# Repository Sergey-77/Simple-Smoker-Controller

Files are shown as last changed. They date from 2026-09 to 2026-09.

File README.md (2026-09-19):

# [PID Temperature Controller for Charbroil Simple Smoker](https://github.com/Sergey-77/Simple-Smoker-Controller)
My smoker had random issues connecting to the phone app, which is how this project started.
The original controller uses a PWM signal with a preset duty cycle to control the smoker's temperature. I recreated this functionality in the code and added the option to integrate a thermocouple for better temperature control using PID. For this setup, I used a MAX31850K thermocouple amplifier and a Type-K thermocouple with a stainless steel tip from adafruit.com.

## Hardware Components
* Microcontroller: Compatible with either the Arduino Nano ESP32 (ESP32-S3) or NodeMCU 1.0 (ESP8266).
* Thermocouple Amplifier: Adafruit MAX31850K 1-Wire Type-K Amplifier.
* Temperature Sensor: Adafruit Type-K Thermocouple.
* Power & Actuation: Powered directly by the smoker's existing 5V power supply, driving the stock heater relay controls.

## Prerequisites
You need to install extra libraries in the Arduino IDE for the MAX31850 Thermocouple Amplifier:

* MAX31850 OneWire by Adafruit
* MAX31850 DallasTemp by Adafruit

If you are using the Arduino Nano ESP32, you need also add the following code block to OneWire.h:
```c++
#elif defined(ARDUINO_ARCH_ESP32)
#define PIN_TO_BASEREG(pin) ((volatile uint32_t *)((digitalPinToGPIONumber(pin)>31)?1:0))
#define PIN_TO_BITMASK(pin) (1 << (digitalPinToGPIONumber(pin)&31))
#define IO_REG_TYPE uint32_t
#define IO_REG_ASM
#define DIRECT_READ(base, mask) ((*((volatile uint32_t *)((base)?GPIO_IN1_REG:GPIO_IN_REG)) & (mask)) ? 1 : 0) // GPIO_IN_ADDRESS
#define DIRECT_MODE_INPUT(base, mask) (*((volatile uint32_t *)((base)?GPIO_ENABLE1_W1TC_REG:GPIO_ENABLE_W1TC_REG)) = (mask)) // GPIO_ENABLE_W1TC_ADDRESS
#define DIRECT_MODE_OUTPUT(base, mask) (*((volatile uint32_t *)((base)?GPIO_ENABLE1_W1TS_REG:GPIO_ENABLE_W1TS_REG)) = (mask)) // GPIO_ENABLE_W1TS_ADDRESS
#define DIRECT_WRITE_LOW(base, mask) (*((volatile uint32_t *)((base)?GPIO_OUT1_W1TC_REG:GPIO_OUT_W1TC_REG)) = (mask)) // GPIO_OUT_W1TC_ADDRESS
#define DIRECT_WRITE_HIGH(base, mask) (*((volatile uint32_t *)((base)?GPIO_OUT1_W1TS_REG:GPIO_OUT_W1TS_REG)) = (mask)) // GPIO_OUT_W1TS_ADDRESS
```

## Wiring Diagram
Both microcontrollers operate natively on 3.3V logic but interface cleanly with the smoker's 5V power supply.
## Cable to original control board

| Blue | Black | Red |
|---|---|---|
| +5V. | DC Common | Heater Relay 3.3V |

## Option A: Using Arduino Nano ESP32

| Target Component | Nano ESP32 Pin | Notes |
|---|---|---|
| Smoker 5V Supply | VIN | Powers the microcontroller from the stock unit |
| Smoker Ground | GND | Common Ground reference |
| Smoker Heater Relay | D3 | Drives the internal heater switching circuit via PWM |
| MAX31850K VCC | 3.3V | Local 3.3V power out from the Nano |
| MAX31850K DATA | D7 | 1-Wire Data line (Requires 4.7kΩ pull-up to 3.3V) |

## Option B: Using NodeMCU 1.0 (ESP8266)

| Target Component | NodeMCU Pin | Notes |
|---|---|---|
| Smoker 5V Supply | VIN (or 5V) | Powers the microcontroller from the stock unit |
| Smoker Ground | GND | Common Ground reference |
| Smoker Heater Relay | D1 | Drives the internal heater switching circuit via PWM |
| MAX31850K VCC | 3V3 | Local 3.3V power out from the NodeMCU |
| MAX31850K DATA | D7 | 1-Wire Data line (Requires 4.7kΩ pull-up to 3.3V) |

------------------------------
## 🌐 Wi-Fi Configuration & Network Modes
The controller can either connect to your Home Wi-Fi network or operate standalone by creating its own Access Point (AP). You can manually force the device into AP mode using the onboard Flash button on NodeMCU or by shorting D2 pin to ground on Nano ESP32 during boot-up or reset.
## Network Behavior Matrix

| Action | Resulting Mode | Network SSID | Password | IP Address |
|---|---|---|---|---|
| Normal Boot | Home Wi-Fi | Your Home Network | Your Password | Assigned by Router |
| Press Flash Button for 3s | Custom AP Mode | Configured Project AP | Configured Pass | 192.168.4.1 |
| Press Flash Button for 10s | Factory Reset AP | smoker | None (Open) | 192.168.4.1 |

ℹ️ Notes on Network Behavior:

* On a normal boot, if home Wi-Fi is not configured, the Custom AP Wi-Fi will start. If the Custom AP is not configured, an open AP will start with the "smoker" SSID.
* The controller will flash the last three digits of its assigned IP address (ignoring leading zeros). For example, 203 will be indicated by two short flashes, a pause, one long flash (representing zero), a pause, and three short flashes.

## 🛠️ How to Trigger Access Point (AP) Mode

   1. Power cycle or press the Reset button on the microcontroller.
   2. Watch for the blue light to blink immediately at power-up.
   3. For Custom AP: On the NodeMCU, press and hold the Flash button; on the Nano ESP32, short pin D2 to ground for 3 seconds.
   4. For Factory Reset AP: On the NodeMCU, press and hold the Flash button; on the Nano ESP32, short pin D2 to ground for 10 seconds. The controller will then spin up an open hotspot named smoker.
   5. Connect your phone or computer to the Wi-Fi network and navigate to http://192.168.4.1 in your browser to access the control panel.

>  **_View source code on_** <a href="https://github.com/Sergey-77/Simple-Smoker-Controller"><i><strong>GitHub</strong>

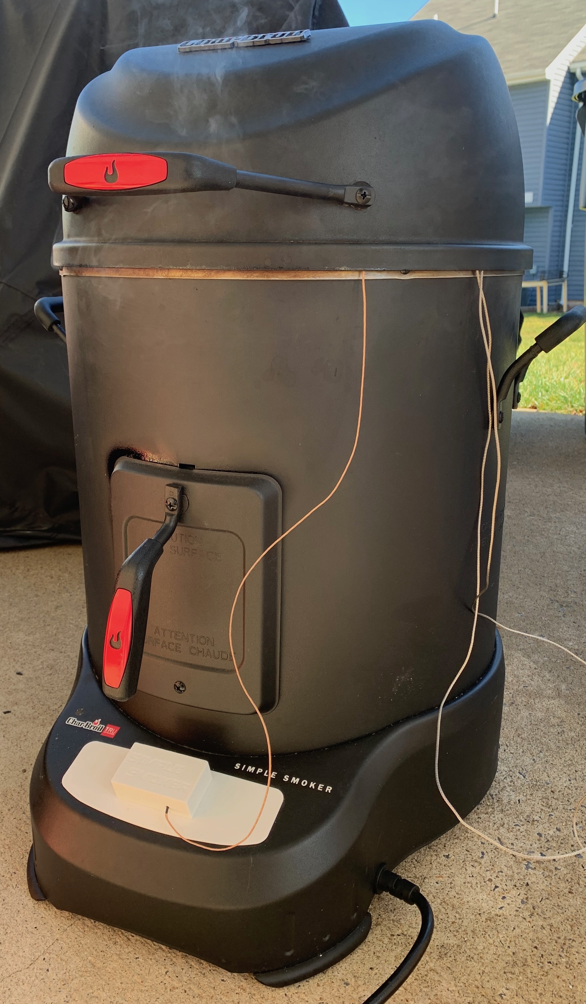
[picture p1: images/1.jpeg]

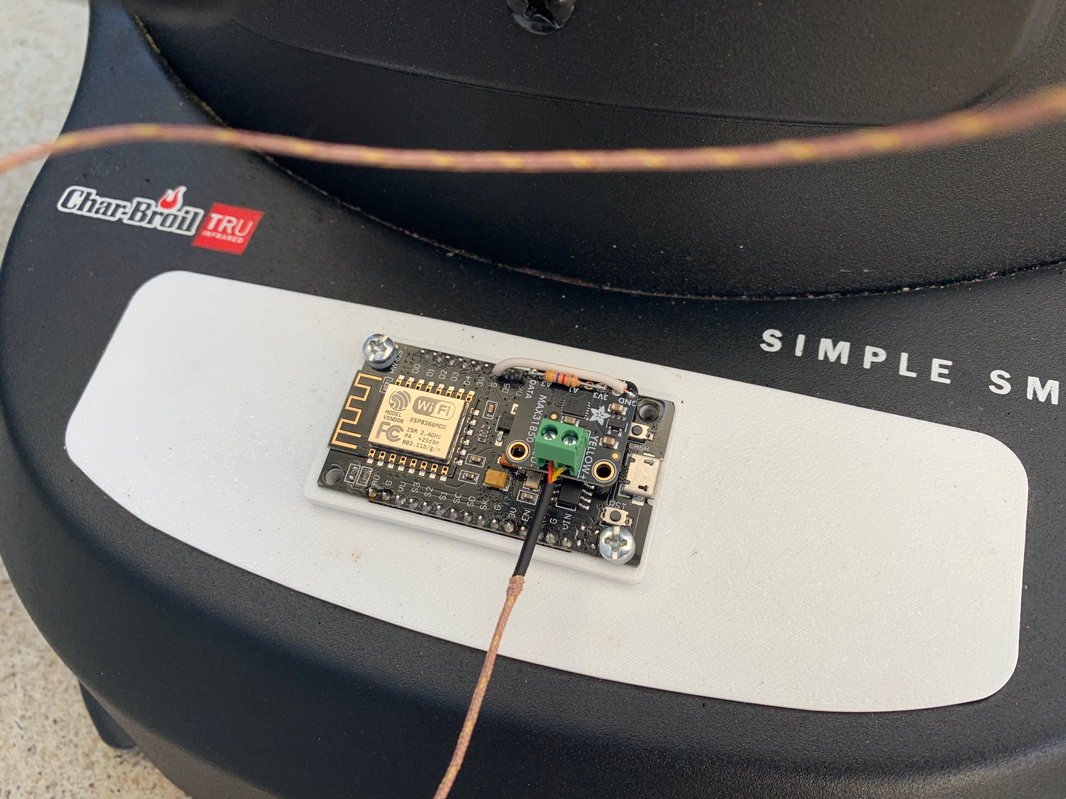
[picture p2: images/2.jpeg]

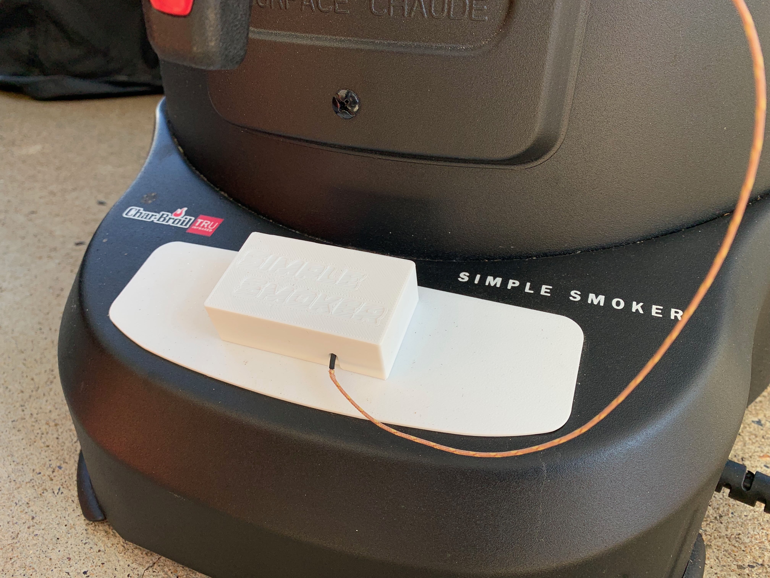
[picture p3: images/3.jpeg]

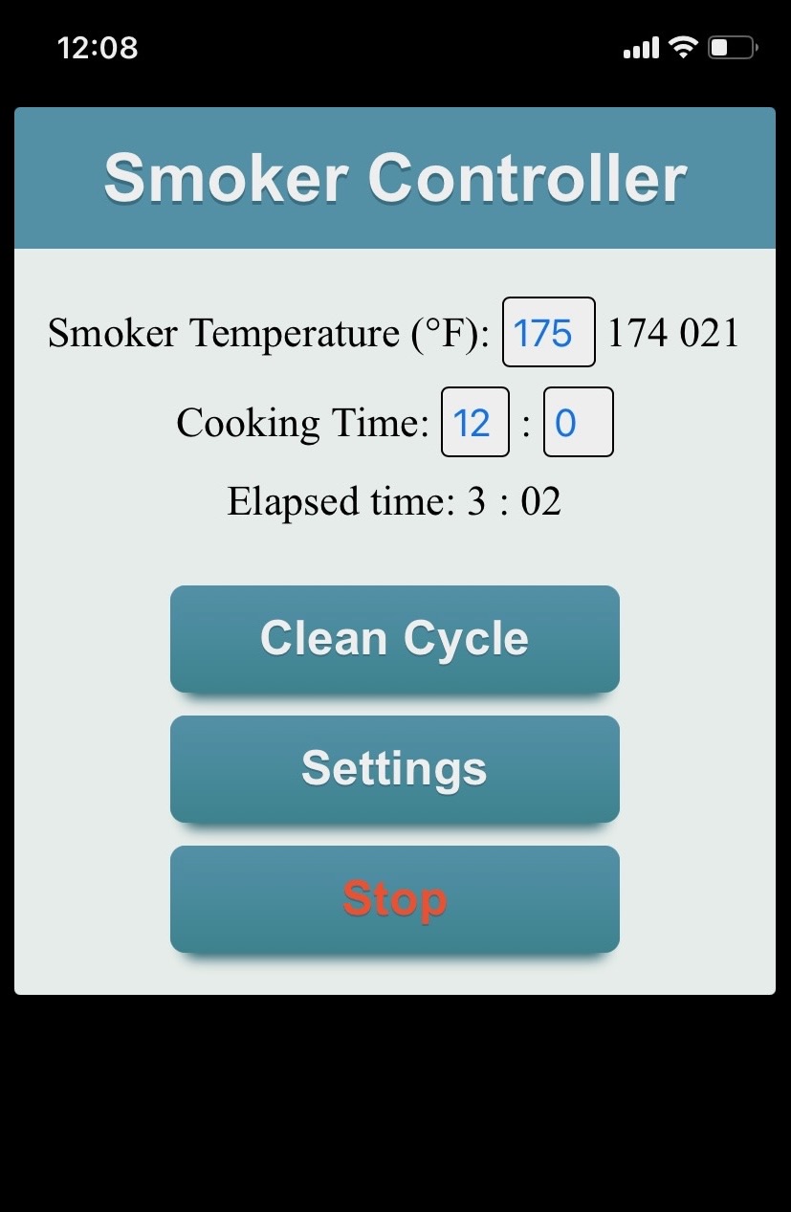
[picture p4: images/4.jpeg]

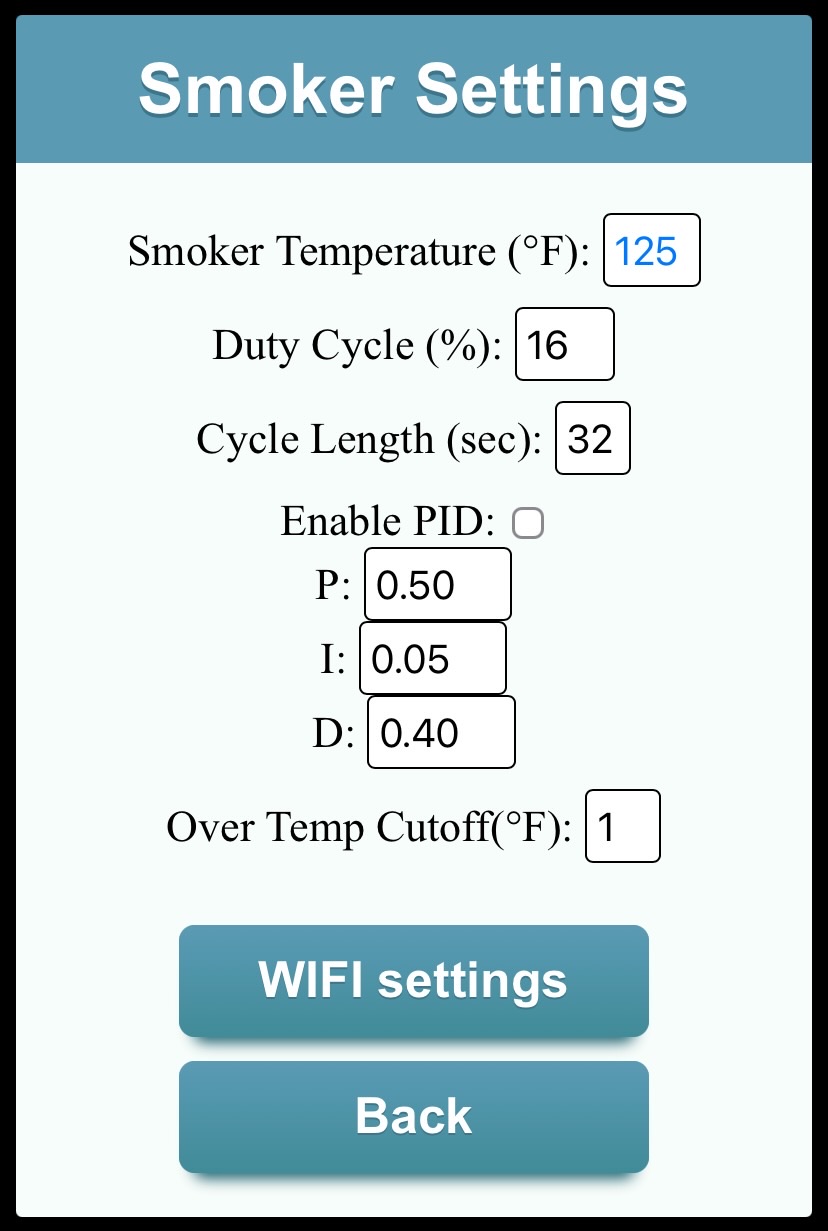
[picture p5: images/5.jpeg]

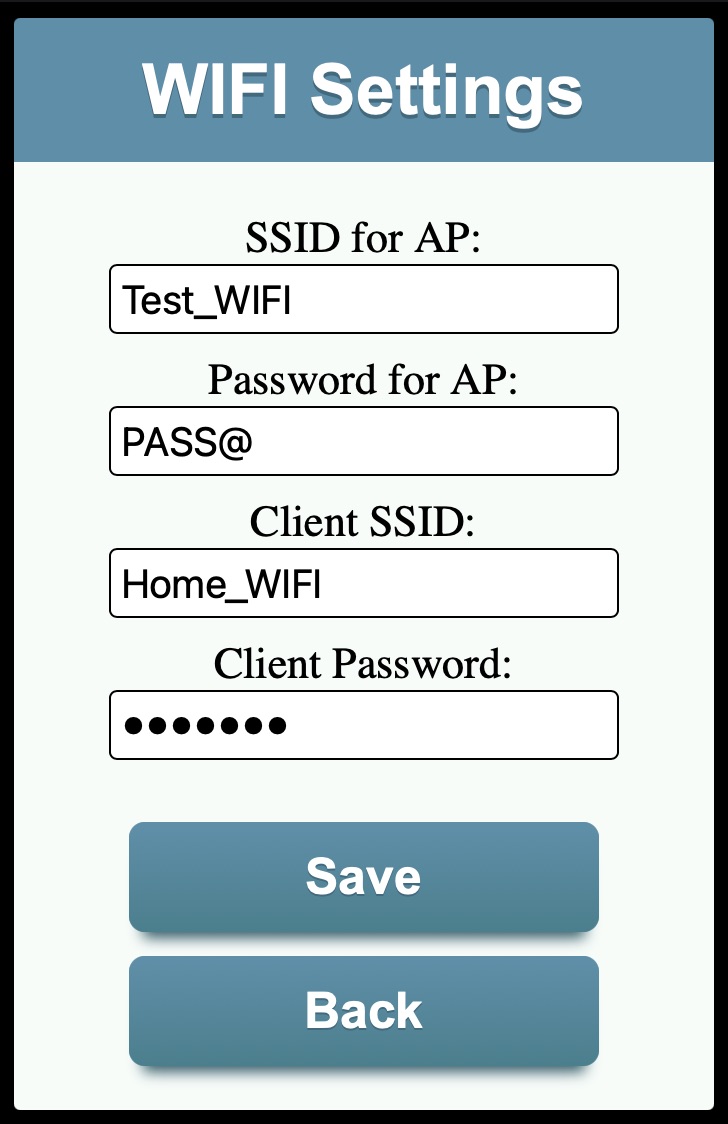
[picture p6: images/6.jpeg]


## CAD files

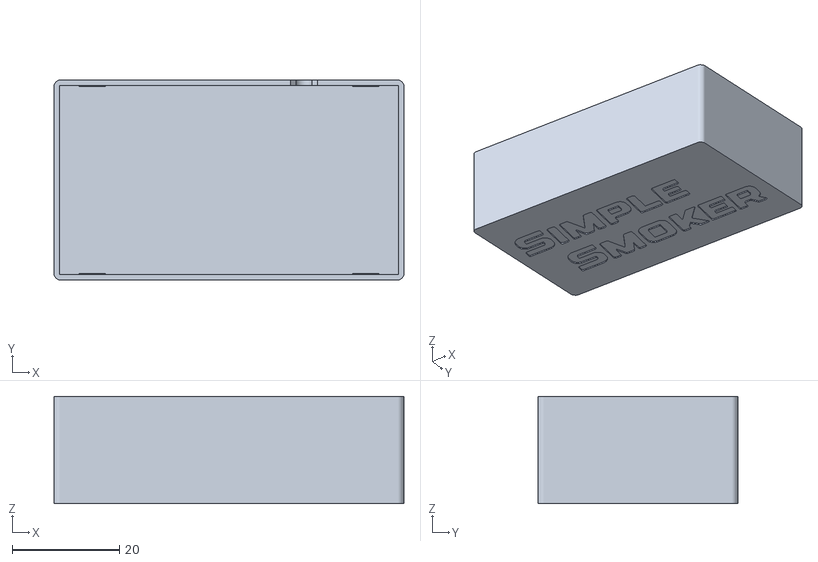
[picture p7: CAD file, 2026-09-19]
Mounting_Panel_NodeMCU/smoker_controller_cover.stl
65.3 x 37.3 x 20.0

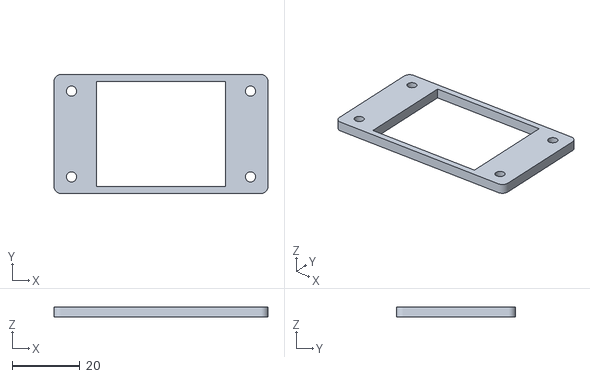
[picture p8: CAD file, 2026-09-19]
Mounting_Panel_NodeMCU/smoker_controller_spacer.stl
63.0 x 35.0 x 3.00

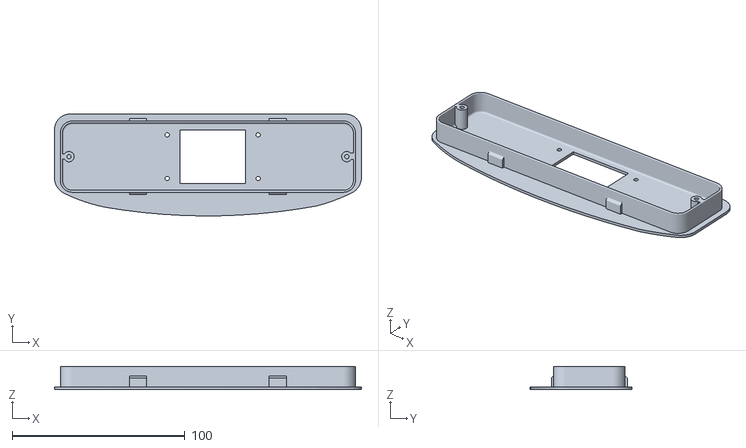
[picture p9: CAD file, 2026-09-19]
Mounting_Panel_NodeMCU/smoker_controller_mounting_panel.stl
177.9 x 59.0 x 13.5

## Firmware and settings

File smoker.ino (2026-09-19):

// NodeMCU ESP8266 Board
/*
    Press flash button for 3 seconds after blue light blink at power up or reset to get Access Point WIFI.
    If button was pressed for 10 seconds default "smoker" AP WIFI will be started. No password needed.
    IP for AP will be 192.168.4.1
*/

/*
The code needs to be added to OneWire.h for Arduino Nano ESP32 support

#elif defined(ARDUINO_ARCH_ESP32)
#define PIN_TO_BASEREG(pin) ((volatile uint32_t *)((digitalPinToGPIONumber(pin)>31)?1:0))
#define PIN_TO_BITMASK(pin) (1 << (digitalPinToGPIONumber(pin)&31))
#define IO_REG_TYPE uint32_t
#define IO_REG_ASM
#define DIRECT_READ(base, mask) ((*((volatile uint32_t *)((base)?GPIO_IN1_REG:GPIO_IN_REG)) & (mask)) ? 1 : 0) // GPIO_IN_ADDRESS
#define DIRECT_MODE_INPUT(base, mask) (*((volatile uint32_t *)((base)?GPIO_ENABLE1_W1TC_REG:GPIO_ENABLE_W1TC_REG)) = (mask)) // GPIO_ENABLE_W1TC_ADDRESS
#define DIRECT_MODE_OUTPUT(base, mask) (*((volatile uint32_t *)((base)?GPIO_ENABLE1_W1TS_REG:GPIO_ENABLE_W1TS_REG)) = (mask)) // GPIO_ENABLE_W1TS_ADDRESS
#define DIRECT_WRITE_LOW(base, mask) (*((volatile uint32_t *)((base)?GPIO_OUT1_W1TC_REG:GPIO_OUT_W1TC_REG)) = (mask)) // GPIO_OUT_W1TC_ADDRESS
#define DIRECT_WRITE_HIGH(base, mask) (*((volatile uint32_t *)((base)?GPIO_OUT1_W1TS_REG:GPIO_OUT_W1TS_REG)) = (mask)) // GPIO_OUT_W1TS_ADDRESS

*/


#if defined(ESP8266)
  #include <ESP8266WiFi.h>
  #define LED D4        // LED on ESP8266
  #define HEATER_PIN D1
  #define BUTTON_PIN 0  // flash button
#elif defined(ESP32)
  #include <WiFi.h>
  #define LED LED_BUILTIN
  #define HEATER_PIN D3
  #define BUTTON_PIN D2
#endif

//#include "smoker.h"
#include "settings_eeprom.h"
#include "html.h"
#include "heater_control.h"

#include "OneWire.h"
#include "DallasTemperature.h"

// Data wire conection from thermocouple module
#define ONE_WIRE_BUS D7

OneWire oneWire(ONE_WIRE_BUS);
DallasTemperature sensors(&oneWire);
WiFiServer server(80);

MainPage main_page;
SettingsPage settings_page;
WifiPage wifi_page;
Data data;

#define PWM_LENGTH 32000

void led_on(){
  #if defined(ESP8266)
  digitalWrite(LED, LOW);
  #else
  digitalWrite(LED, HIGH);
  #endif
}

void led_off(){
  #if defined(ESP8266)
  digitalWrite(LED, HIGH);
  #else
  digitalWrite(LED, LOW);
  #endif  
}

void blink_ip(int ip){
  int ii;
  if (ip<10)ii = 2;
  else if (ip<100)ii = 1;
  for(; ii < 3; ii++){
    int i, zero;
    if(ii == 0 and ip>99){
      i = ip / 100;
      ip -= (i*100);
    }
    else if (ii == 1){
      if (ip>9){
        i = ip / 10;
        ip -= (i*10);
      }else zero = 1;
    }
    else if (ii == 2){
      if (ip){
         i = ip;
        ip = 0;
      }
      else zero =1;
    }
    for (;i>0;i--){
      led_on();
      delay(50);
      led_off();
      delay(500);
    }
     if (zero){
      led_on();
      delay(800);
      led_off();
      delay(500);
      zero = 0;
    }
    delay(2000);
  }
}
unsigned long get_pwm_duty_cycle_length(){
  int index = (smoker_temp_setpoint - 125)/25;
  if(index < 0 || index > 16)index = 0;
  int duty_cycle_preset = settings.pwm_preset[index];
  pwm_duty_cycle = duty_cycle_preset;
  return PWM_LENGTH * duty_cycle_preset / 100;
}

void setup() {
  pinMode(BUTTON_PIN, INPUT_PULLUP);
  pinMode(LED, OUTPUT);
  pinMode(HEATER_PIN, OUTPUT);
  led_off();
  get_settings_eeprom();
  delay(500);
  int button_pressed = 0;
  while(digitalRead(BUTTON_PIN) == LOW){
    delay(1000);
    button_pressed++;
  }
  if (button_pressed > 5) {
    WiFi.softAP("smoker");
  }
  else if (button_pressed > 0) {
    WiFi.softAP(settings.SSID_AP, settings.PASSWORD_AP);
  }
  else if(settings.SSID[0] != '\0'){
    WiFi.hostname("smoker");
    WiFi.mode(WIFI_STA);
    WiFi.begin (settings.SSID, settings.PASSWORD);
    while (WiFi.status() != WL_CONNECTED) {
        delay(500);
    }
    // LED blink last three digits of IP 
    IPAddress ip = WiFi.localIP();
    blink_ip(ip[3]);
  }
  
  else if (settings.SSID_AP[0] != '\0') {
    WiFi.softAP(settings.SSID_AP, settings.PASSWORD_AP);
  }
  else{
    WiFi.softAP("smoker");
  } 
  server.begin(); 
  pwm_on_phase = get_pwm_duty_cycle_length();
  sensors.begin();
}

void loop() {
  WiFiClient client = server.accept();
  if (client) {
  String request = client.readStringUntil('\r');
  if (request.indexOf("temperature=") != -1){
    main_page.extractAndSetTemperature(request);
    pwm_on_phase = get_pwm_duty_cycle_length();
    client.print(main_page.html());
  }
  else if (request.indexOf("cooking_time_h=") != -1){
    main_page.extractAndSetTimer(request); 
    client.print(main_page.html());
  }
  else if (request.indexOf("setup") != -1){
    settings_page.extractAndSetParameters(request);
    client.print(settings_page.html());
  }
  else if ((request.indexOf("clean_cycle") != -1) && running == 0){
    if(cleaning_cycle_tmp){
      smoker_temp_setpoint = smoker_temp_setpoint_tmp;
      cooking_time_hours = cooking_time_hours_tmp;
      cooking_time_minutes = cooking_time_minutes_tmp;
    }
    else{
      smoker_temp_setpoint_tmp = smoker_temp_setpoint;
      cooking_time_hours_tmp = cooking_time_hours;
      cooking_time_minutes_tmp = cooking_time_minutes;
      smoker_temp_setpoint = 525;
      cooking_time_hours = 0;
      cooking_time_minutes = 30;
    }
    cleaning_cycle_tmp ^= 1;
    pwm_on_phase = get_pwm_duty_cycle_length();
    client.print(main_page.html());
  }
  else if (request.indexOf("start") != -1){
    int index = request.indexOf("start");
    char validation[3];
    validation[2] = '\0';
    validation[0] = request[index + 6];
    validation[1] = request[index + 7];
    if(start_button_validation == atoi(validation)){
      start_button_validation++;
      if(start_button_validation>99)start_button_validation=0;
      run ^=1;
      if(run == 0){
        running = 0;
      }
    }
    client.print(main_page.html());
  }
  else if (request.indexOf("GET /data.html") != -1){
    client.print(data.html());
  }
  else if (request.indexOf("wifi") != -1){
    wifi_page.process_request(request);
    client.print(wifi_page.html());
  }
  else {
    client.print(main_page.html());
  }
  // client.stop(); 
  }
  const unsigned long time_now = millis();
  if(run == 1 && running == 1 ){
    elapsedTime = time_now - startTime;
    elapsed_time_h = elapsedTime/3600000;
    elapsed_time_m = (elapsedTime - (elapsed_time_h * 3600000))/60000;
    if(elapsed_time_h > cooking_time_hours ){
      run = 0;
      running = 0;
    }
    if(elapsed_time_h == cooking_time_hours && elapsed_time_m >= cooking_time_minutes){
      run = 0;
      running = 0;
    }
  }
  if(run == 1 && running == 0 ){
    startTime = time_now;
    running = 1;
    if(settings.pid_enabled){
      heater_controll_pid(smoker_temp_setpoint, thermocouple, 1);
    }
  }
  if(running){
    millis_buffer = time_now - pwm_start;
    if(millis_buffer > PWM_LENGTH){
      pwm_start = time_now;
      millis_buffer = 0;
    }
    if(millis_buffer < pwm_on_phase){
      led_on();
      digitalWrite(HEATER_PIN, HIGH);
    }
    else{
      led_off();
      digitalWrite(HEATER_PIN, LOW);
    }
  }
  else {
    led_off();
    digitalWrite(HEATER_PIN, LOW);
  }
  if ((time_now - temp_update_time) > 5000UL){
    sensors.requestTemperatures();
    thermocouple = sensors.getTempCByIndex(0)*1.8 + 32; //with celsius to fahrenheit conversion
    if(isnan(thermocouple))thermocouple = -127;
    temp_update_time = time_now;
  }
  if(settings.pid_enabled && running && ((time_now - pid_update_time) > 30000UL)){
    pwm_duty_cycle = heater_controll_pid(smoker_temp_setpoint, thermocouple);
    pwm_on_phase = PWM_LENGTH * pwm_duty_cycle / 100;
    pid_update_time = time_now;
  } 
}

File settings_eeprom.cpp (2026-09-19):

#include "settings_eeprom.h"
#include <EEPROM.h>
#include <cstdio>

settings_struct settings;

void get_settings_eeprom(){
	EEPROM.begin(sizeof(settings));
	EEPROM.get(0, settings);
	if(settings.MEMORY_INITIALIZED != 1){
		settings.MEMORY_INITIALIZED = 1;
		sprintf(settings.SSID, "");
		sprintf(settings.PASSWORD, "");
		sprintf(settings.SSID_AP, "");
		sprintf(settings.PASSWORD_AP, "");
		settings.pid_enabled = 0;
		settings.Kp = 0.5;
		settings.Ki = 0.03;
		settings.Kd = 0.4;
		settings.temp_high = 0;
		settings.pwm_preset[0] = 20;
		settings.pwm_preset[1] = 25;
		settings.pwm_preset[2] = 30;
		settings.pwm_preset[3] = 35;
		settings.pwm_preset[4] = 40;
		settings.pwm_preset[5] = 45;
		settings.pwm_preset[6] = 50;
		settings.pwm_preset[7] = 55;
		settings.pwm_preset[8] = 60;
		settings.pwm_preset[9] = 65;
		settings.pwm_preset[10] = 70;
		settings.pwm_preset[11] = 75;
		settings.pwm_preset[12] = 80;
		settings.pwm_preset[13] = 85;
		settings.pwm_preset[14] = 90;
		settings.pwm_preset[15] = 95;
		settings.pwm_preset[16] = 100;
		EEPROM.put(0, settings); 
		EEPROM.commit();
	}
}

void store_settings_eeprom(){
	EEPROM.put(0, settings); 
	EEPROM.commit();
}

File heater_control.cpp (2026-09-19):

#include "heater_control.h"
#include "settings_eeprom.h"
#include <cmath>

int heater_controll_pid(int setpoint, float temperature, int first_run){
	int pwm;
	static int preheated;
	static float errPrev, errSum;
	float errSum2;
	int index = (setpoint - 125)/25;
  if(index < 0 || index > 16)index = 0;
  int offset = settings.pwm_preset[index];
	float error = setpoint - temperature;
	if(first_run){
		errPrev = error;
		preheated = 0;
		errSum = errSum2 = 0;
	}
	float delta = error - errPrev;
	if((abs(delta) < 1 && temperature > setpoint - 15) || preheated){
		errSum2 = settings.Ki * error;
		preheated = 1;
	}else{
		errSum2 = 0;
	}
	errPrev = error;
	pwm = offset + settings.Kp * error + errSum + errSum2 + settings.Kd * delta;
	if(pwm > 100){
		pwm = 100;
		if(errSum2 > 0){
			errSum2 = 0;
		}
	}
	if(pwm < 0){
		pwm = 0;
		if(errSum2 < 0){
			errSum2 = 0;
		}
	}
	errSum += errSum2;
	if(pwm < 5){
		pwm = 0;
	}
	if(temperature > 600 || temperature < 0) pwm = 0;
	if(settings.temp_high > 0 && temperature > setpoint + settings.temp_high) pwm = 0;
	return pwm;
}

/*
type_heater_presets heater_presets[17] = {
	{125,19.35},
	{150,25.00}, //not in simple smoker
	{175,29.03},
	{200,35.00}, //not in simple smoker
	{225,38.71},
	{250,45.16},
	{275,50.00},
	{300,54.84},
	{325,59.38},
	{350,64.52},
	{375,68.75},
	{400,74.19},
	{425,78.13},
	{450,83.87},
	{475,90.32},
	{500,93.55},
	{525,100.00}
};
*/

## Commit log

2026-11-06 Added one hour temperature chart to main page.
2026-11-10 Move heater_control.cpp to src/smoker/heater_control.cpp
2026-11-10 Move heater_control.h to src/smoker/heater_control.h
2026-11-10 Move temperature_chart.cpp to src/smoker/temperature_chart.cpp
2026-11-10 Move temperature_chart.h to src/smoker/temperature_chart.h
